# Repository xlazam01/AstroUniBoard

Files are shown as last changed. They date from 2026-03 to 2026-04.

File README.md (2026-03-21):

# AstroUniBoard

A custom STM32G0B1-based telescope controller board focused on **focuser and rotator control**. Firmware is a port of [OnStepX](https://groups.io/g/onstep/wiki/home) to a custom PCB, with added SHT31 weather sensor support and DFU bootloader management.

## Repository Structure

```
AstroUniBoard/
├── FW/                     # Firmware (PlatformIO / Arduino / OnStepX)
│   ├── src/                # OnStepX source tree + custom config
│   ├── platformio.ini      # Build configuration
│   └── tools/              # Firmware manager MCP server (DFU upload)
├── HW/                     # Hardware (PCB designs, schematics — KiCad)
└── docs/
    ├── HARDWARE.md         # Pin assignments and hardware overview
    └── FIRMWARE.md         # Build and upload guide
```

## Hardware

| | |
|---|---|
| **MCU** | STM32G0B1CBT6 (ARM Cortex-M0+ @ 64 MHz) |
| **Flash / RAM** | 128 KB / 144 KB SRAM |
| **Package** | 48-pin LQFP |
| **Stepper Drivers** | 2× TMC2209 (UART, shared bus) |
| **NV Storage** | 24AA64 I2C EEPROM (8 KB) |
| **Weather Sensor** | SHT31 (temperature + humidity, I2C) |
| **Interface** | USB CDC (native USB PA11/PA12) |
| **Upload** | DFU bootloader (ROM) |

### Axes

| Axis | Function | Driver | UART Address |
|---|---|---|---|
| AXIS3 | Rotator | TMC2209 | 1 |
| AXIS4 | Focuser | TMC2209 | 0 |

Mount axes (AXIS1/AXIS2) are disabled — this board is focuser/rotator only.

See [docs/HARDWARE.md](docs/HARDWARE.md) for full pin assignments.

## Firmware

Based on **OnStepX** — advanced telescope controller firmware with LX200 protocol compatibility, ASCOM support, and stepper motor control.

### Custom additions in this port

- `STM32G0B1.h` — HAL implementation for STM32G0B1CBT6
- `Pins.AUB_FocRot.h` — Custom pinmap (model AUB_FOCROT = 25)
- SHT31 weather sensor support (not in upstream OnStepX)
- `:EDFU#` command — jump to DFU ROM bootloader for firmware updates
- Activity LED (PB4) driven by focuser/rotator movement

### Build status

- Flash: **93.3%** (122,244 / 131,072 bytes)
- RAM: **8.2%**
- Compiler: ARM GCC, `-Os -std=gnu++17`
- Hardware tested and functional

### Quick start

1. Install [PlatformIO](https://platformio.org/)
2. Open the `FW/` folder in VS Code
3. Build: `Ctrl+Alt+B` (environment: `nucleo_g0b1re`)
4. First upload: put board in DFU via BOOT0 switch, then `Ctrl+Alt+U`
5. Subsequent uploads: send `:EDFU#` via serial to enter DFU, then upload

See [docs/FIRMWARE.md](docs/FIRMWARE.md) for full build and upload instructions.

## Serial Commands

| Command | Action |
|---|---|
| `:EDFU#` | Jump to DFU ROM bootloader (firmware upload) |
| `:ERESET#` | Reset MCU |
| `:ENVRESET#` | Wipe NV memory (takes effect on next boot) |

Plus the full [OnStepX LX200 command set](https://groups.io/g/onstep/wiki/OnStep-Command-Reference).

## Communication

- **Port:** USB CDC (virtual COM port, no driver needed on Linux/Mac; WinUSB on Windows)
- **Baud rate:** 115200
- **Protocol:** LX200 / OnStepX command set
- **Compatible clients:** ASCOM OnStep driver, INDI OnStep driver, Android OnStep apps, Sky Planetarium

## Tools

### Firmware Manager MCP Server

`FW/tools/firmware_manager/server.py` — MCP server that automates DFU firmware updates from Claude Code or any MCP client.

```bash
pip install -r FW/tools/firmware_manager/requirements.txt
python FW/tools/firmware_manager/server.py
```

Key tool: `enter_dfu_and_upload(port, firmware_path)` — sends `:EDFU#`, waits for re-enumeration, uploads via dfu-util.

## License

Firmware is licensed under the GPL (inherited from OnStepX). See [FW/src/LICENSE](FW/src/LICENSE).

## Credits

- OnStepX firmware by [Howard Dutton](http://www.stellarjourney.com) and contributors
- STM32G0B1 HAL port and AstroUniBoard hardware by the project author

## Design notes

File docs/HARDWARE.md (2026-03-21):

# AstroUniBoard — Hardware Reference

## MCU

| Property | Value |
|---|---|
| Part | STM32G0B1CBT6 |
| Architecture | ARM Cortex-M0+ |
| Clock | 64 MHz |
| Flash | 128 KB |
| RAM | 144 KB SRAM |
| Package | 48-pin LQFP |

## Motor Control

| Function | Pin | Notes |
|---|-----|---|
| AXIS3 ENABLE | PB7 | Rotator — active LOW |
| AXIS3 DIR | PB8 | Rotator |
| AXIS3 STEP | PB9 | Rotator |
| AXIS4 ENABLE | PB0 | Focuser — active LOW |
| AXIS4 DIR | PB1 | Focuser |
| AXIS4 STEP | PB2 | Focuser |

OnStepX axis convention: AXIS3 = Rotator, AXIS4 = Focuser. AXIS1/AXIS2 (mount) are disabled.

## TMC2209 UART (shared bus, USART2)

| Function | Pin | Notes |
|---|-----|---|
| TX | PA2 | USART2 TX, shared by both drivers |
| RX | PA3 | USART2 RX, shared by both drivers |

Baud rate: 460800. TMC2209 addresses hardwired via MS1/MS2: AXIS3 = addr 1, AXIS4 = addr 0.

## I2C Bus

| Function | Pin | Notes |
|---|-----|---|
| SCL | PA9 | 24AA64 EEPROM + SHT31 sensor |
| SDA | PA10 | 24AA64 EEPROM + SHT31 sensor |

| Device | Address | Purpose |
|---|---|---|
| 24AA64 | 0x50 | 8 KB NV storage (focuser/rotator position, settings) |
| SHT31 | 0x44 | Temperature + humidity sensor |

## USB (Native USB CDC)

| Function | Pin | Notes |
|---|-----|---|
| USB D- | PA11 | |
| USB D+ | PA12 | |

Appears as virtual COM port. Baud rate: 115200.

## Status & UI

| Function | Pin | Active | Notes |
|---|-----|---|---|
| Status LED | PB12 | LOW | Power/status indicator |
| Activity LED | PB4 | LOW | Blinks during focuser/rotator movement |
| Button LEFT | PA14 | — | Reserved, not used |
| Button RIGHT | PB6 | — | Reserved, not used |

## Auxiliary / Reserved

| Function | Pin | Notes |
|---|-----|---|
| UART6 TX | PA4 | Reserved for future use |
| UART6 RX | PA5 | Reserved for future use |
| LIMIT | PA1 | Not used |
| AUX1 | PC13 | Not used |
| AUX2 | PC14 | Not used |
| AXIS3 DIAG | PA7 | TMC2209 diag pin, not used |

## PlatformIO Board Mapping

The board is built using the `btt_ebb42_v1_1` PlatformIO target — this board uses the same STM32G0B1CBT6 chip and provides the correct STM32duino support. DFU upload targets flash address `0x08000000`.

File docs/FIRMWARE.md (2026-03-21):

# AstroUniBoard — Firmware Build & Upload Guide

## Prerequisites

- [VS Code](https://code.visualstudio.com/) with [PlatformIO extension](https://platformio.org/install/ide?install=vscode)
- Open the `FW/` folder as the PlatformIO project root

## Build

Open `FW/` in VS Code and use PlatformIO:

- **GUI:** PlatformIO sidebar → `nucleo_g0b1re` environment → Build
- **Keyboard:** `Ctrl+Alt+B`
- **CLI:** `pio run -e nucleo_g0b1re`

Build output: `FW/.pio/build/nucleo_g0b1re/firmware.bin`

### Build configuration summary

| Setting | Value |
|---|---|
| Platform | ststm32 |
| Board | btt_ebb42_v1_1 |
| Framework | Arduino |
| Upload protocol | DFU |
| Optimization | `-Os -std=gnu++17` |
| USB CDC flags | `-DUSBCON -DUSBD_USE_CDC -DHAL_PCD_MODULE_ENABLED` |

### Flash budget

| Metric | Value |
|---|---|
| Flash used | 122,244 / 131,072 bytes (93.3%) |
| RAM used | ~8.2% |

> Debug level must stay at `ON`, not `VERBOSE`. VERBOSE adds ~15 KB of string literals and overflows the 128 KB flash.

## Upload

### Via DFU (normal workflow)

1. Connect the board via USB
2. Send `:EDFU#` via any serial terminal at 115200 baud
   - Board disconnects from CDC and re-enumerates as STM32 DFU device
3. Upload: `Ctrl+Alt+U` in VS Code, or the Firmware Manager tool (see below)
4. Board auto-resets and runs new firmware
5. **Note:** "Error 74" at end of DFU upload is harmless (DFU leave status quirk)

### First upload (no firmware yet)

Board has no `:EDFU#` command, so enter DFU manually:

1. Hold BOOT0 switch, press RESET (or power-cycle with BOOT0 held)
2. Release BOOT0 — board enumerates as STM32 DFU device
3. Upload with `Ctrl+Alt+U`

### Firmware Manager MCP Server (automated)

`FW/tools/firmware_manager/server.py` provides an MCP server for one-step DFU upload from Claude Code.

```bash
pip install -r FW/tools/firmware_manager/requirements.txt
python FW/tools/firmware_manager/server.py
```

**Recommended:** `enter_dfu_and_upload(port, firmware_path)` — handles the full workflow.

```python
enter_dfu_and_upload(
    "COM6",
    "f:/Projekty/AstroUniBoard/FW/.pio/build/nucleo_g0b1re/firmware.bin"
)
```

Available tools:

| Tool | Description |
|---|---|
| `list_ports()` | List available COM ports |
| `enter_dfu(port)` | Send `:EDFU#` command |
| `upload_firmware(firmware_path)` | Upload .bin via dfu-util (device must already be in DFU) |
| `enter_dfu_and_upload(port, path, wait_seconds=3)` | Complete workflow (recommended) |
| `build_firmware(project_dir, environment)` | Build via PlatformIO CLI |
| `serial_read(port, baudrate, duration_seconds)` | Read serial output |

## Configuration

### Primary: `FW/src/Config.h`

```c
#define PINMAP          AUB_FOCROT    // Custom board
#define SERIAL_A_BAUD   115200        // USB CDC
#define WEATHER         SHT31         // I2C 0x44
#define STATUS_LED      ON
#define AXIS1_DRIVER_MODEL  OFF       // No mount
#define AXIS2_DRIVER_MODEL  OFF       // No mount
#define AXIS3_DRIVER_MODEL  TMC2209   // Rotator
#define AXIS4_DRIVER_MODEL  TMC2209   // Focuser
```

### Extended: `FW/src/Extended.config.h`

```c
#define DEBUG           ON            // Use ON, never VERBOSE
#define SERIAL_DEBUG    SerialUSB
#define NV_WIPE         OFF
```

## Serial Commands

| Command | Action |
|---|---|
| `:EDFU#` | Jump to DFU ROM bootloader |
| `:ERESET#` | Reset MCU |
| `:ENVRESET#` | Wipe NV memory on next boot |

Full OnStepX LX200 command set applies for focuser and rotator control.

## Troubleshooting

### "No DFU capable USB device available"
Device not in DFU mode yet. Increase `wait_seconds` to 4–5, or check BOOT0.

### "could not open port COMX"
Port is in use. Close any serial monitors before uploading.

### Board not responding after upload
Check that `SerialUSB` (not `Serial`) is used for USB CDC. The firmware uses `SerialUSB` explicitly.

### dfu-util not found
PlatformIO bundles dfu-util. Path: `C:\Users\<user>\.platformio\packages\tool-dfuutil\bin\dfu-util.exe`

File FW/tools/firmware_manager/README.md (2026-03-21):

# Firmware Manager MCP Server

Manages firmware updates and DFU mode entry for the AstroUniBoard FocuserRotator (OnStepX).

## Prerequisite
- `dfu-util` must be installed (bundled with PlatformIO)
- `pip install -r requirements.txt`

## Tools

### `list_ports()`
List available COM ports.

**Returns:** List of port names

---

### `enter_dfu(port)`
Send `:EDFU#` command to jump to bootloader.

**Parameters:**
- `port` (str): Serial port (e.g., "COM6")

**Returns:** Status message

**Note:** Device will reboot into DFU mode. Wait 2-3 seconds before uploading.

---

### `upload_firmware(firmware_path)`
Upload firmware using dfu-util.

**Parameters:**
- `firmware_path` (str): Absolute path to .bin firmware file

**Returns:** Upload status and output

**Example:**
```python
upload_firmware("f:/Projekty/AstroUniBoard/FW - FocuserRotator/.pio/build/nucleo_g0b1re/firmware.bin")
```

---

### `enter_dfu_and_upload(port, firmware_path, wait_seconds=3)` - **RECOMMENDED**
Complete workflow: Send DFU command -> Wait -> Upload firmware.

**Parameters:**
- `port` (str): Serial port (e.g., "COM6")
- `firmware_path` (str): Absolute path to .bin firmware file
- `wait_seconds` (int): Seconds to wait after DFU command (default: 3)

**Returns:** Complete workflow status

**Example:**
```python
enter_dfu_and_upload(
    "COM6",
    "f:/Projekty/AstroUniBoard/FW - FocuserRotator/.pio/build/nucleo_g0b1re/firmware.bin",
    3
)
```

---

## Usage

### Starting the Server
```bash
python tools/firmware_manager/server.py
```

### Typical Workflow

**Option 1: All-in-one (Recommended)**
```python
enter_dfu_and_upload(
    "COM6",
    "f:/Projekty/AstroUniBoard/FW - FocuserRotator/.pio/build/nucleo_g0b1re/firmware.bin"
)
```

**Option 2: Manual steps**
```python
# Step 1: Send DFU command
enter_dfu("COM6")

# Step 2: Wait manually (3 seconds)

# Step 3: Upload
upload_firmware("f:/Projekty/AstroUniBoard/FW - FocuserRotator/.pio/build/nucleo_g0b1re/firmware.bin")
```

---

## Troubleshooting

### "No DFU capable USB device available"
**Cause:** Device not in DFU mode yet
**Solution:**
- Increase `wait_seconds` parameter (try 4-5 seconds)
- Manually reset device before upload

### "could not open port 'COMX'"
**Cause:** Port is in use
**Solution:**
- Close any serial monitors
- Close VSCode serial monitor
- Wait for port to be released

### "dfu-util not found"
**Cause:** dfu-util not in PATH
**Solution:**
- Verify path: `c:\Users\marti\.platformio\packages\tool-dfuutil\bin\dfu-util.exe`
- Server uses hardcoded path, should work automatically

---

## Configuration

The server is pre-configured for your environment:
- **DFU command:** `:EDFU#` (OnStepX custom command)
- **Serial baud:** 115200
- **dfu-util path:** `c:\Users\marti\.platformio\packages\tool-dfuutil\bin\dfu-util.exe`
- **Upload address:** `0x08000000` (STM32 flash start)
- **Upload mode:** `:leave` (device auto-reboots after upload)
- **Build output:** `.pio/build/nucleo_g0b1re/firmware.bin`

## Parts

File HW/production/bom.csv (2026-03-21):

Designator | Footprint | Quantity | Value | LCSC Part #
C1, C10, C11, C33 | 0402 | 4 | 1uF
C12, C15, C17, C8, C9 | 0402 | 5 | 100nF
C13, C16, C29 | 0805 | 3 | 10u/25V
C14, C31, C32 | 0402 | 3 | 10uF
C18, C7 | 0402 | 2 | 22n/50V
C19, C20, C21, C22, C23, C25, C26, C27, C30 | 0402 | 9 | 100n/50V
C2, C3 | 0805 | 2 | 10uF/25V
C24, C28 | 0402 | 2 | 10uF/10V
C4, C5 | 0402 | 2 | 10pF
C6 | 0402 | 1 | 100n
D1, D2, D3, D4 | 0603 | 4 | LED RED 0603
D23 | D_SMA | 1 | D_Small
F1, F2 | 0603 | 2 | SMD0603P050TF
H1, H2, H3, H4 | MountingHole_2.2mm_M2_DIN965_Pad | 4 | MountingHole_Pad
H5, H6, H7, H8 | MountingHole_3.2mm_M3_DIN965_Pad | 4 | MountingHole_Pad
J10, J3, J5, J8, J9 | JST_PH_B4B-PH-K_1x04_P2.00mm_Vertical | 5 | Conn_01x04
J2, J7 | USB_C_Receptacle_G-Switch_GT-USB-7010ASV | 2 | MC-311D
J4 | JST_PH_B3B-PH-K_1x03_P2.00mm_Vertical | 1 | Conn_01x03
J6 | BarrelJack_GCT_DCJ200-10-A_Horizontal | 1 | 5.5/2.1 Barell DC2
L4 | L_5.5x5.1mm | 1 | L_Small
LEFT/BOOT1, RIGHT1, RST1 | SW_Push_SPST_NO_Alps_SKRK | 3 | TS-1088-AR02016
R1, R2 | 0402 | 2 | 22R
R10, R11, R19, R20 | 0805 | 4 | 0.11R/0805
R12, R24 | 0402 | 2 | 1k
R13, R15, R27, R3, R4, R5, R9 | 0402 | 7 | 10k
R14, R18, R6 | 0402 | 3 | 510R
R16, R17, R7, R8 | 0402 | 4 | 5k1
R21 | 0402 | 1 | 100k
R22 | 0402 | 1 | 6k34(10k7)
R23 | 0402 | 1 | 2k
R25, R26 | 0402 | 2 | 22k
TP1, TP2, TP3 | TestPoint_Micro | 3 | TestPoint
U1 | SOT-23 | 1 | ME6231
U12 | SOT-23-6 | 1 | ME3116
U2, U3 | QFN-28-1EP_5x5mm_P0.5mm_EP3.75x3.75mm_ThermalVias | 2 | ~
U4 | SOT-23-5 | 1 | 24AA64T-I/OT
U5 | LQFP-48_7x7mm_P0.5mm | 1 | STM32G0B1CBTx
U6 | LQFN-16-1EP_3x3mm_P0.5mm_EP1.7x1.7mm | 1 | CH334P
U8 | Sensirion_DFN-8-1EP_2.5x2.5mm_P0.5mm_EP1.1x1.7mm | 1 | SHT31A-DIS
Y1 | Crystal_SMD_3225-4Pin_3.2x2.5mm | 1 | TAXM8M4RDBCCT2T / 8MHz
Y2 | Crystal_SMD_3225-4Pin_3.2x2.5mm | 1 | TAXM12M4RDBCCT2T / 12MHz

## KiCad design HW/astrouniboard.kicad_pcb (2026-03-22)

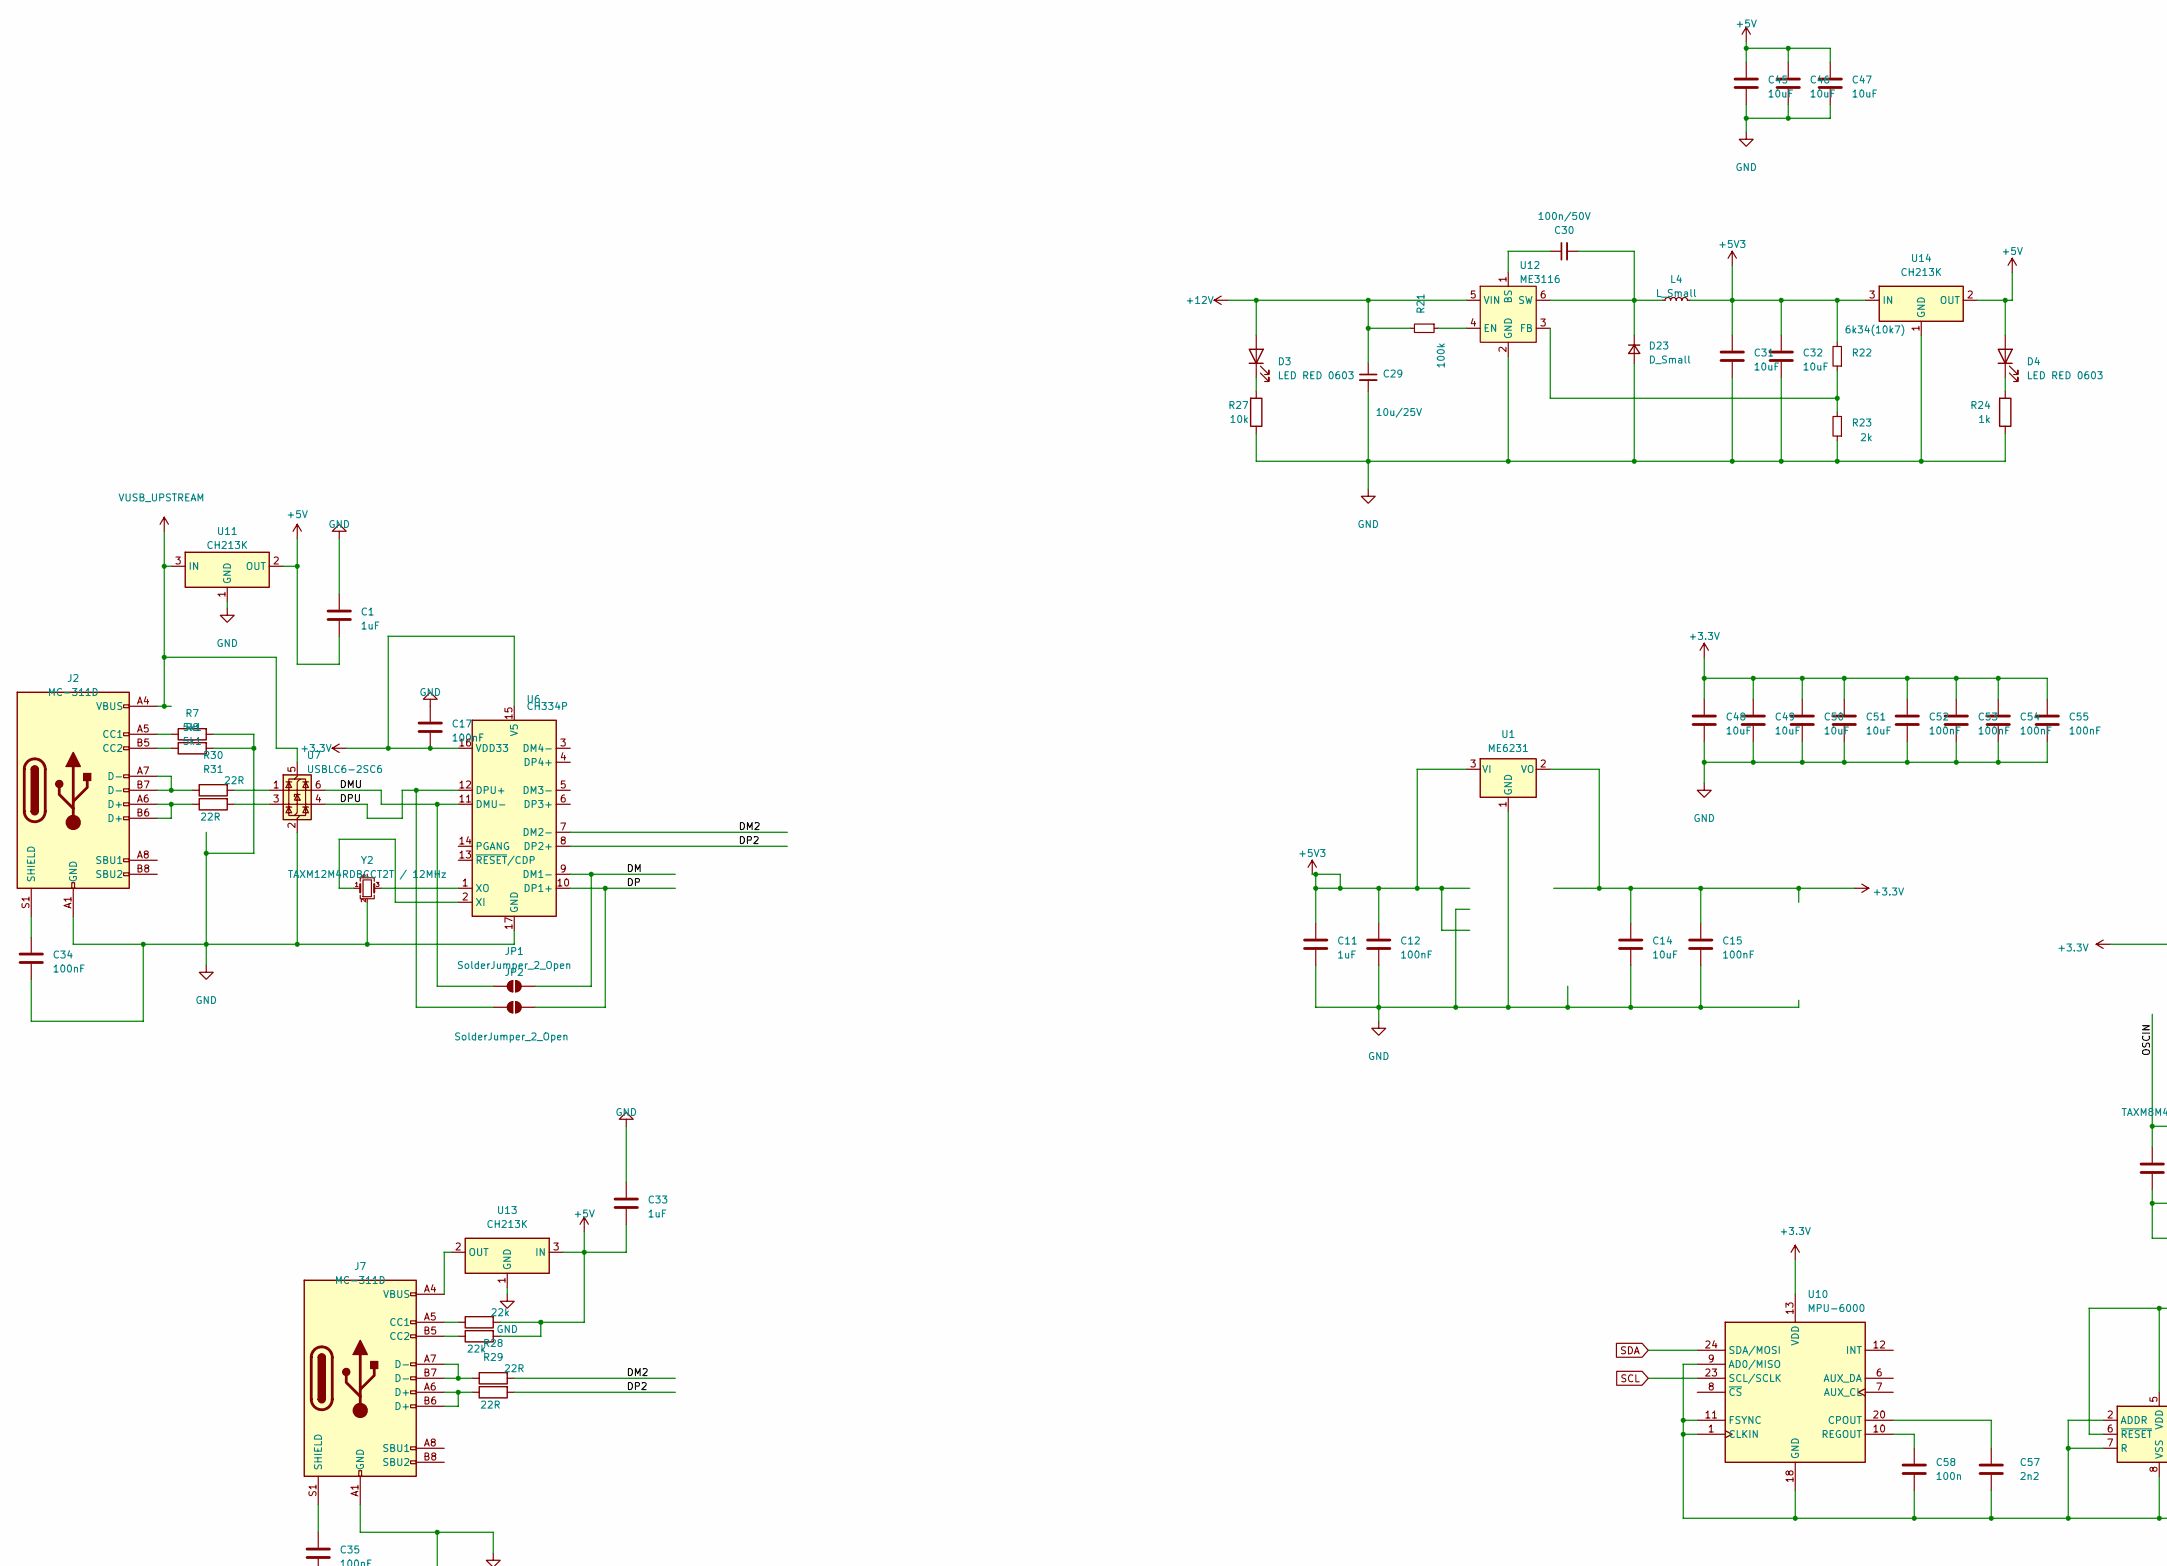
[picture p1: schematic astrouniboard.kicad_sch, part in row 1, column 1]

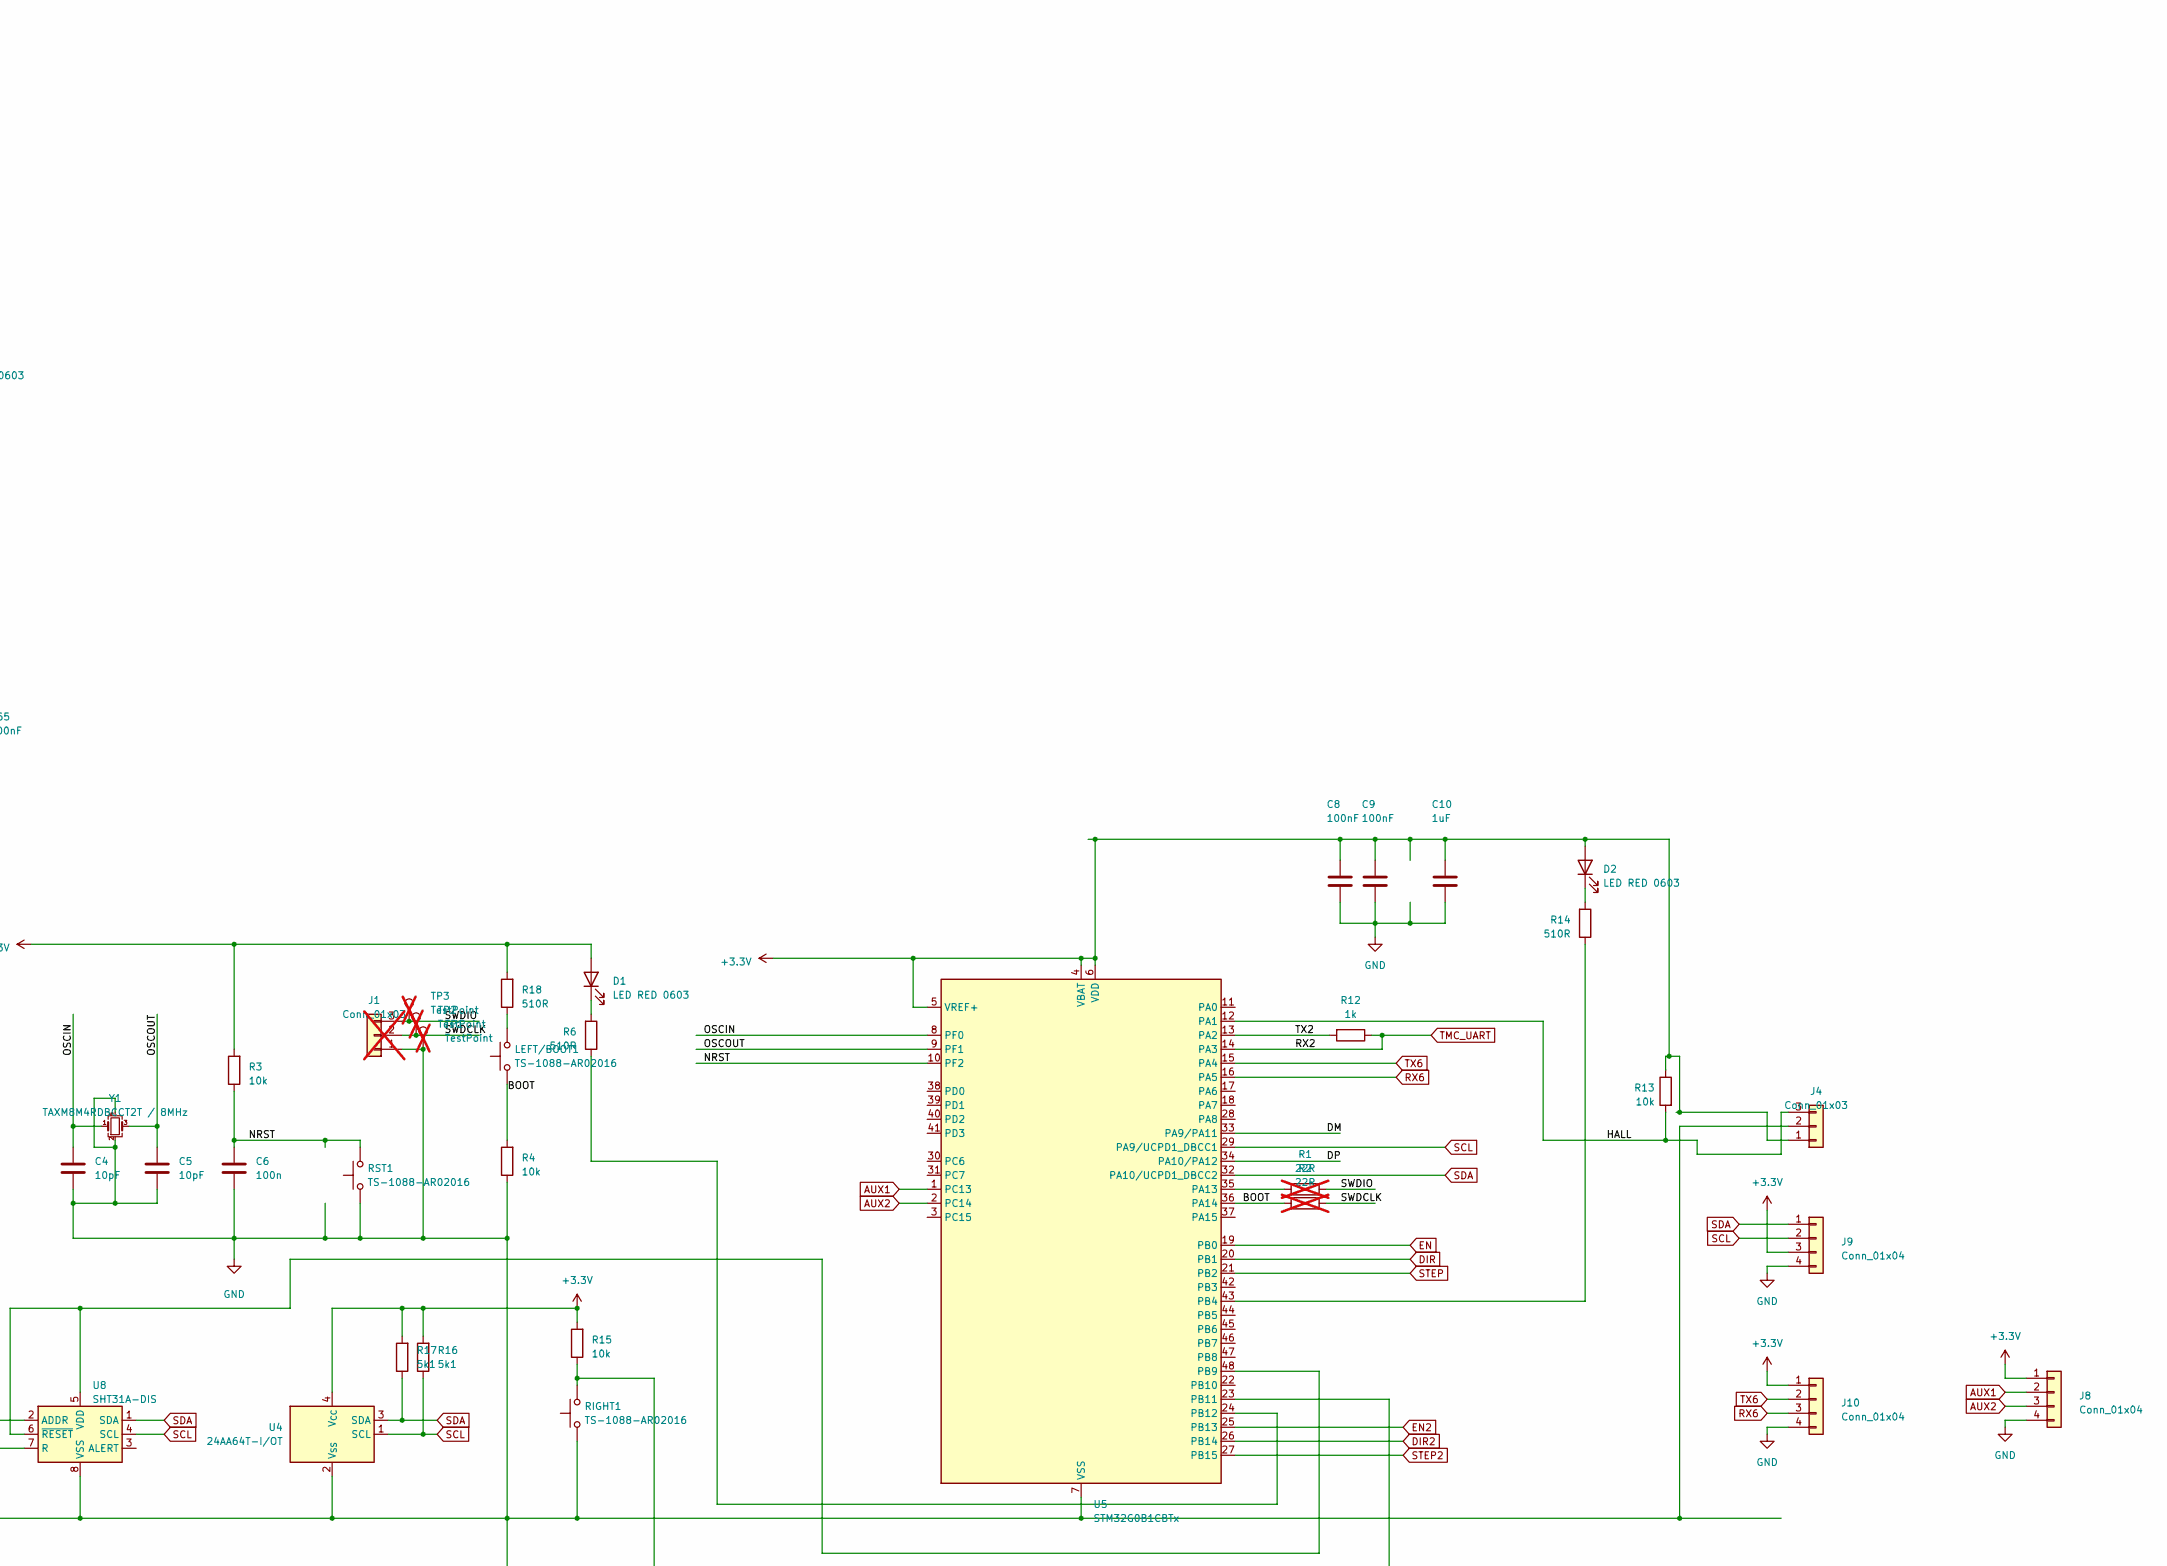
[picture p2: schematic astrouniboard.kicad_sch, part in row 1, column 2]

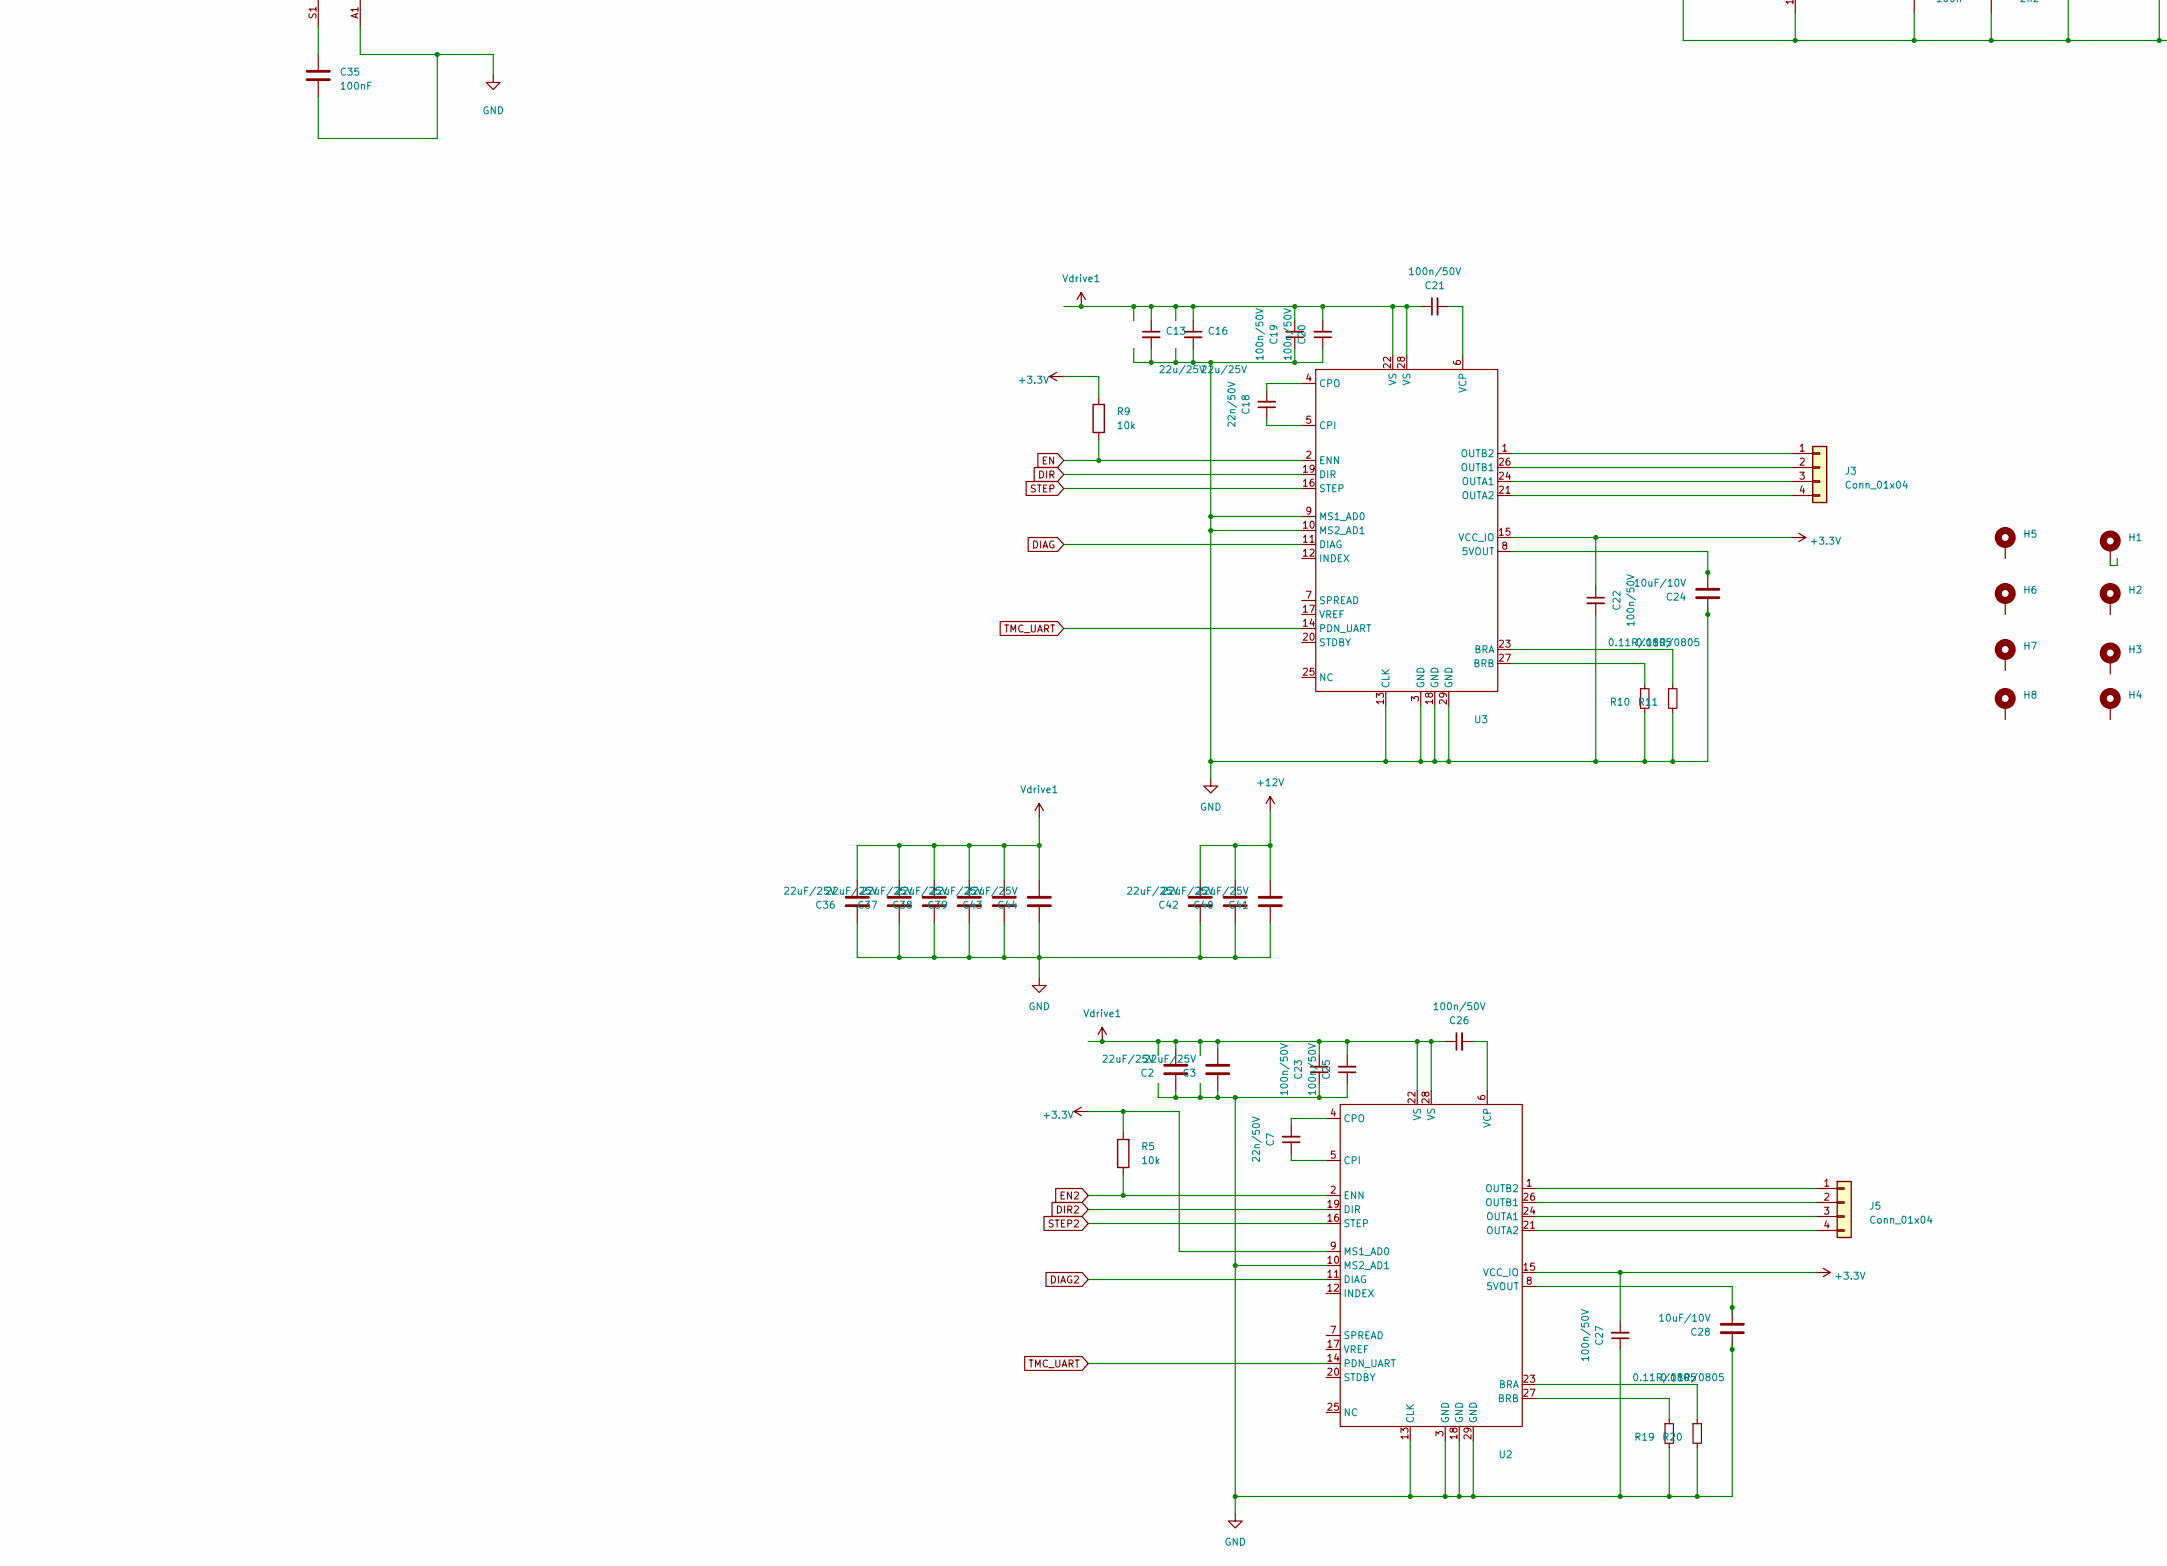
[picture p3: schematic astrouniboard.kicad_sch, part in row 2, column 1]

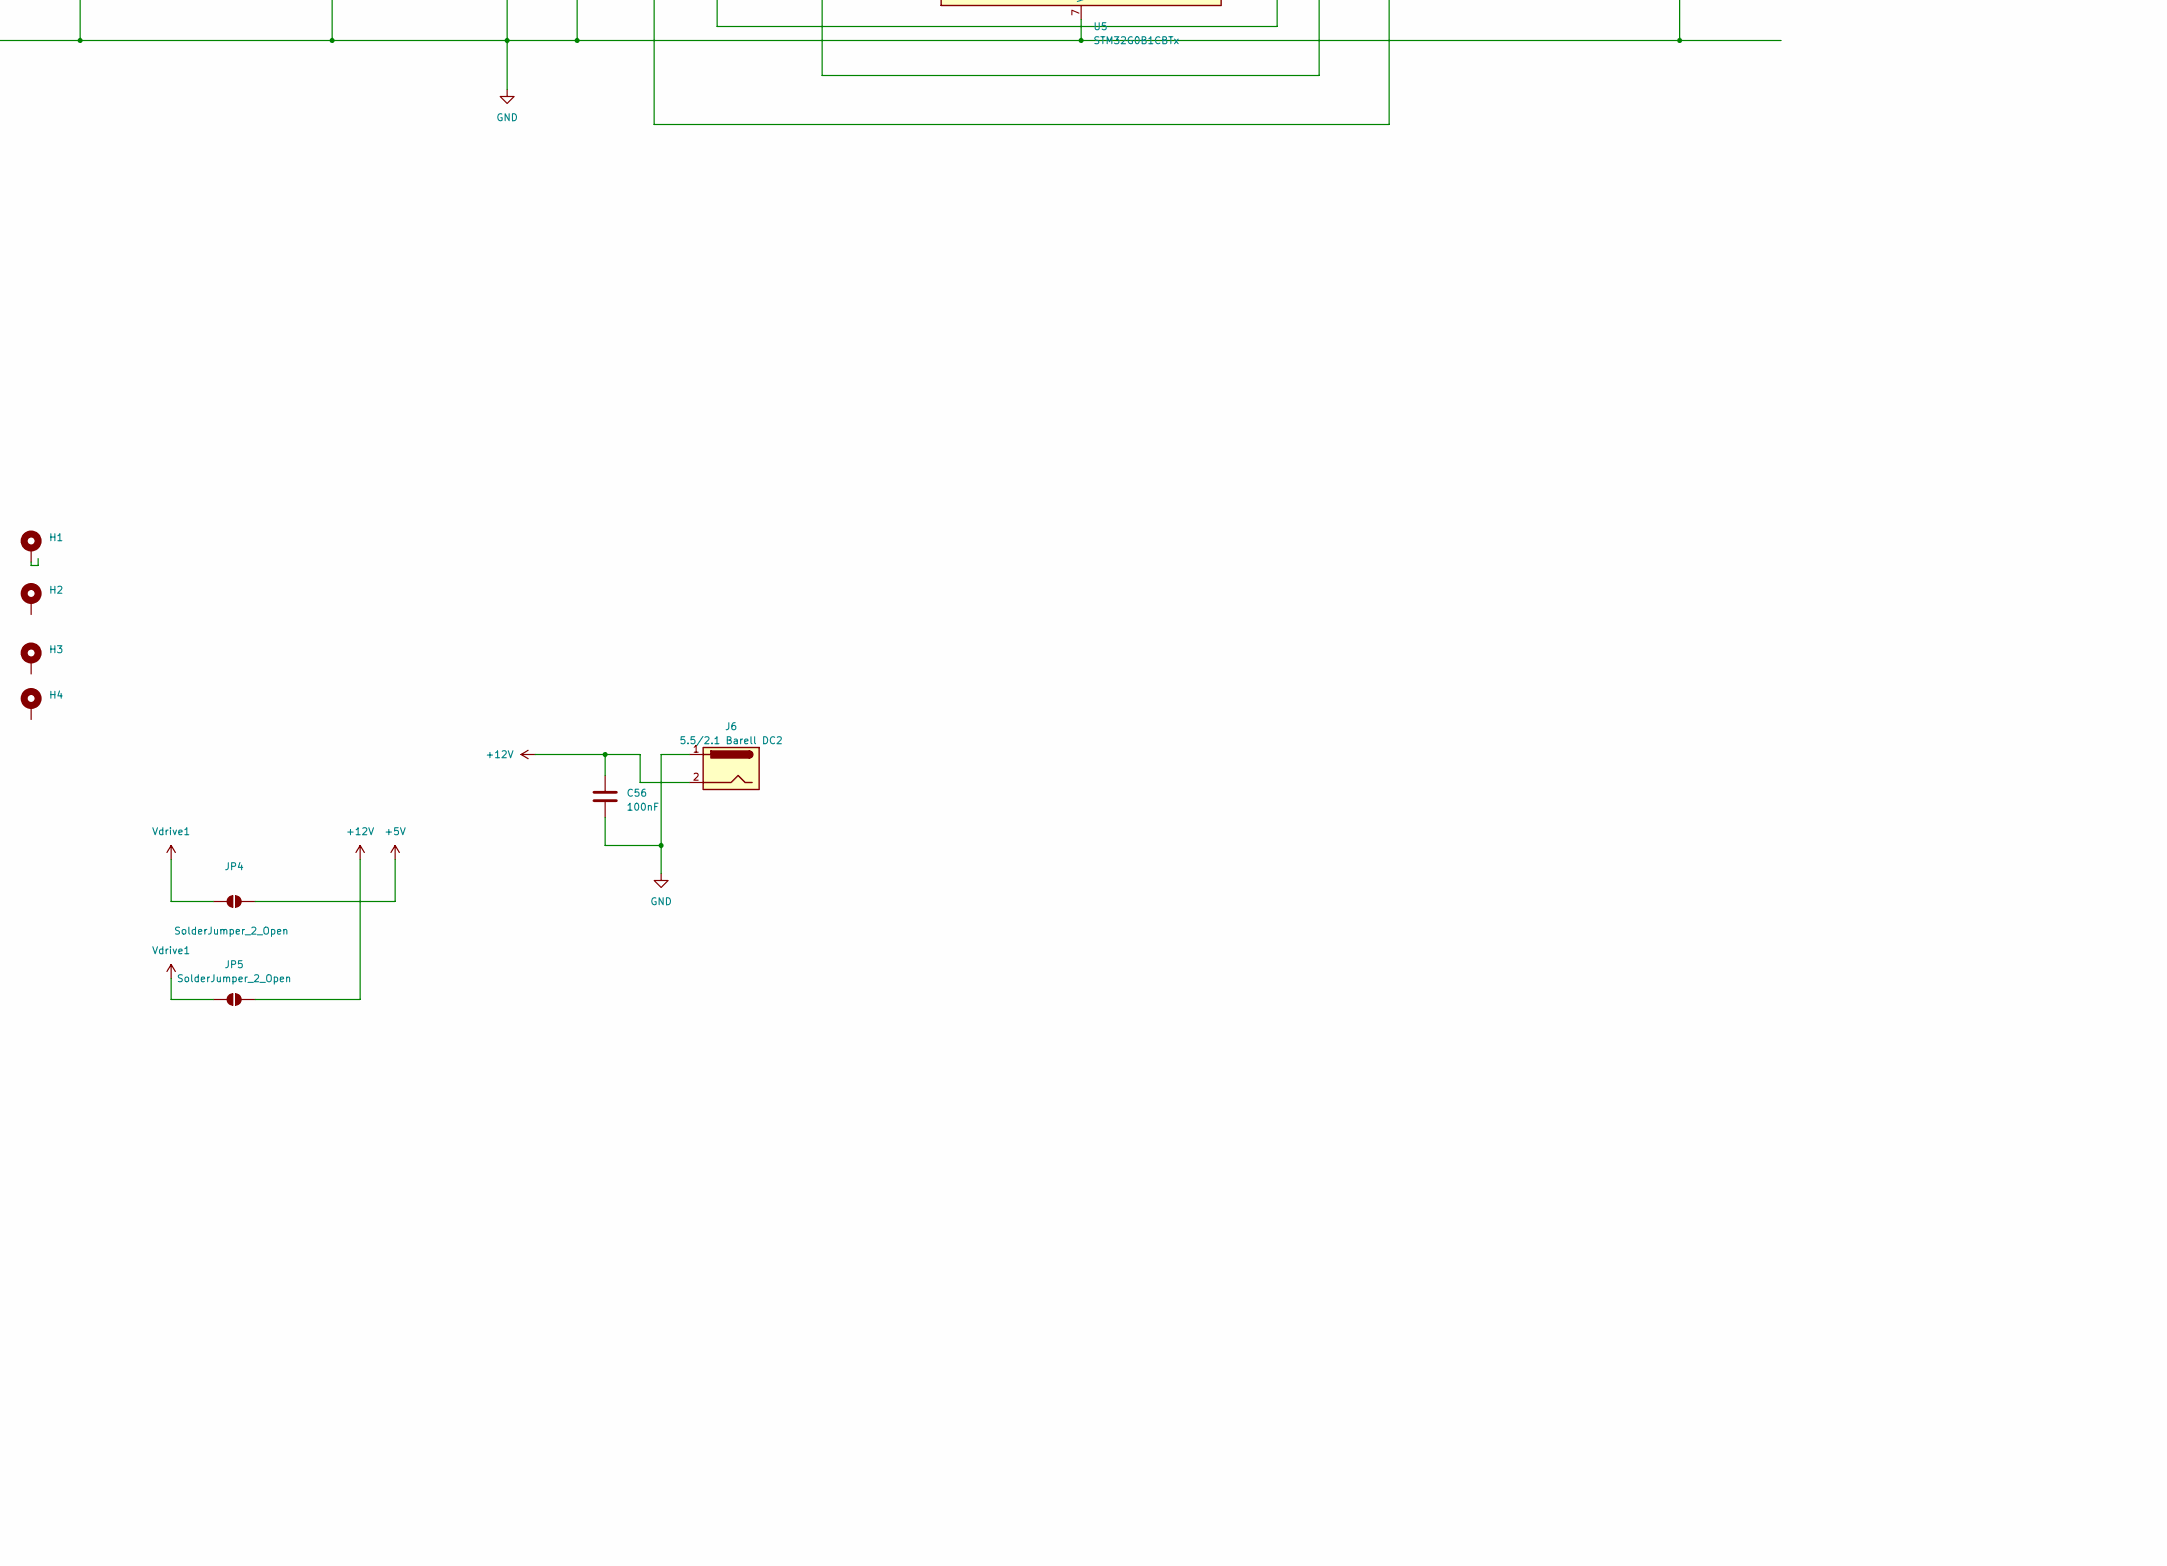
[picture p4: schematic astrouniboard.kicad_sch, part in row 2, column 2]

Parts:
C1, C10, C11, C33: 1uF; C_0402_1005Metric
C2, C3, C36, C37, C38, C39, C40, C41, C42, C43, C44: 22uF/25V; C_0805_2012Metric
C4, C5: 10pF; C_0402_1005Metric
C6, C58: 100n; C_0402_1005Metric
C7, C18: 22n/50V; C_0402_1005Metric
C8, C9, C12, C15, C17, C34, C35, C52, C53, C54, C55, C56: 100nF; C_0402_1005Metric
C13, C16: 22u/25V; C_0805_2012Metric
C14, C31, C32, C45, C46, C47, C48, C49, C50, C51: 10uF; C_0402_1005Metric
C19, C20, C21, C22, C23, C25, C26, C27, C30: 100n/50V; C_0402_1005Metric
C24, C28: 10uF/10V; C_0402_1005Metric
C29: 10u/25V; C_0805_2012Metric
C57: 2n2; C_0402_1005Metric
D1, D2, D3, D4: LED RED 0603; LED_0402_1005Metric
D23: D_Small; D_SMA
H1, H2, H3, H4: MountingHole_Pad; MountingHole_2.2mm_M2_DIN965_Pad
H5, H6, H7, H8: MountingHole_Pad; MountingHole_3.2mm_M3_DIN965_Pad
J1: Conn_01x03; JST_PH_B3B-PH-K_1x03_P2.00mm_Vertical; not fitted
J2, J7: MC-311D; USB_C_Receptacle_G-Switch_GT-USB-7010ASV
J3, J8, J9, J10: Conn_01x04; JST_PH_B4B-PH-K_1x04_P2.00mm_Vertical
J4: Conn_01x03; JST_PH_B3B-PH-K_1x03_P2.00mm_Vertical
J5: Conn_01x04; JST_PH_S4B-PH-K_1x04_P2.00mm_Horizontal
J6: 5.5/2.1 Barell DC2; AMASS_XT30PW-M_1x02_P2.50mm_Horizontal
JP1, JP2: SolderJumper_2_Open; Micro SolderJumper
JP4, JP5: SolderJumper_2_Open; SolderJumper-2_P1.3mm_Open_RoundedPad1.0x1.5mm
L4: L_Small; L_5.5x5.1mm
LEFT/BOOT1: TS-1088-AR02016; SW_Push_SPST_NO_Alps_SKRK
R1, R2: 22R; R_0402_1005Metric; not fitted
R3, R4, R5, R9, R13, R15, R27: 10k; R_0402_1005Metric
R6, R14, R18: 510R; R_0402_1005Metric
R7, R8, R16, R17: 5k1; R_0402_1005Metric
R10, R11, R19, R20: 0.11R/0805; R_0805_2012Metric
R12, R24: 1k; R_0402_1005Metric
R21: 100k; R_0402_1005Metric
R22: 6k34(10k7); R_0402_1005Metric
R23: 2k; R_0402_1005Metric
R25, R26: 22k; R_0402_1005Metric
R28, R29, R30, R31: 22R; R_0402_1005Metric
RIGHT1: TS-1088-AR02016; SW_Push_SPST_NO_Alps_SKRK
RST1: TS-1088-AR02016; SW_Push_SPST_NO_Alps_SKRK
TP1, TP2, TP3: TestPoint; TestPoint_Micro; not fitted
U1: ME6231; SOT-23
U2, U3: QFN-28-1EP_5x5mm_P0.5mm_EP3.75x3.75mm_ThermalVias
U4: 24AA64T-I/OT; SOT-23-5
U5: STM32G0B1CBTx; LQFP-48_7x7mm_P0.5mm
U6: CH334P; LQFN-16-1EP_3x3mm_P0.5mm_EP1.7x1.7mm
U7: USBLC6-2SC6; SOT-23-6
U8: SHT31A-DIS; Sensirion_DFN-8-1EP_2.5x2.5mm_P0.5mm_EP1.1x1.7mm
U10: MPU-6000; InvenSense_QFN-24_4x4mm_P0.5mm
U11, U13, U14: CH213K; SOT-23
U12: ME3116; SOT-23-6
Y1: TAXM8M4RDBCCT2T / 8MHz; Crystal_SMD_3225-4Pin_3.2x2.5mm
Y2: TAXM12M4RDBCCT2T / 12MHz; Crystal_SMD_3225-4Pin_3.2x2.5mm

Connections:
+3.3V: C8.1, C9.1, C10.1, C14.1, C15.1, C17.2, C22.1, C27.2, C48.1, C49.1, C50.1, C51.1, C52.1, C53.1, C54.1, C55.1, D1.2 (A), D2.2 (A), J4.1, J8.1, J9.3, J10.1, R3.2, R5.2, R9.2, R13.1, R15.2, R16.2, R17.2, R18.2, U1.2 (VO), U2.9 (MS1_AD0), U2.15 (VCC_IO), U3.15 (VCC_IO), U4.4 (V_{CC}), U5.4 (VBAT), U5.5 (VREF+), U5.6 (VDD), U6.15 (V5), U6.16 (VDD33), U10.13 (VDD)
+5V: C1.2, C33.2, C45.1, C46.1, C47.1, D4.2 (A), JP4.2 (B), R25.2, R26.2, U11.2 (OUT), U13.3 (IN), U14.2 (OUT)
+5V3: C11.1, C12.1, C31.1, C32.1, L4.2, R22.2, U1.3 (VI), U14.3 (IN)
/BOOT: LEFT/BOOT1.1, R4.2, U5.36 (PA14)
/DM: JP1.2 (B), U5.33 (PA9/PA11), U6.9 (DM1-)
/DM2: R28.2, U6.7 (DM2-)
/DMU: JP1.1 (A), U6.11 (DMU-), U7.6 (I/O1)
/DP: JP2.2 (B), U5.34 (PA10/PA12), U6.10 (DP1+)
/DP2: R29.2, U6.8 (DP2+)
/DPU: JP2.1 (A), U6.12 (DPU+), U7.4 (I/O2)
/HALL: J4.3, R13.2, U5.12 (PA1)
/NRST: C6.1, R3.1, RST1.2, U5.10 (PF2)
/OSCIN: C4.1, U5.8 (PF0), Y1.1
/OSCOUT: C5.1, U5.9 (PF1), Y1.3
/TX2: R12.2, U5.13 (PA2)
AUX1: J8.2, U5.1 (PC13)
AUX2: J8.3, U5.2 (PC14)
DIAG: U3.11 (DIAG)
DIAG2: U2.11 (DIAG)
DIR: U3.19 (DIR), U5.20 (PB1)
DIR2: U2.19 (DIR), U5.26 (PB14)
EN: R9.1, U3.2 (ENN), U5.19 (PB0)
EN2: R5.1, U2.2 (ENN), U5.25 (PB13)
GND: C1.1, C2.1, C3.1, C4.2, C5.2, C6.2, C8.2, C9.2, C10.2, C11.2, C12.2, C13.2, C14.2, C15.2, C16.2, C17.1, C19.1, C20.1, C22.2, C23.1, C24.1, C25.1, C27.1, C28.1, C29.2, C31.2, C32.2, C33.1, C34.2, C35.2, C36.1, C37.1, C38.1, C39.1, C40.1, C41.1, C42.1, C43.1, C44.1, C45.2, C46.2, C47.2, C48.2, C49.2, C50.2, C51.2, C52.2, C53.2, C54.2, C55.2, C56.2, C57.2, C58.2, D23.2 (A), J2.A1 (GND), J2.A12 (GND), J2.B1 (GND), J2.B12 (GND), J4.2, J6.1, J7.A1 (GND), J7.A12 (GND), J7.B1 (GND), J7.B12 (GND), J8.4, J9.4, J10.4, R4.1, R7.2, R8.2, R10.2, R11.2, R19.2, R20.2, R23.1, R24.1, R27.1, RIGHT1.1, RST1.1, U1.1 (GND), U2.3 (GND), U2.10 (MS2_AD1), U2.13 (CLK), U2.18 (GND), U2.29 (GND), U3.3 (GND), U3.9 (MS1_AD0), U3.10 (MS2_AD1), U3.13 (CLK), U3.18 (GND), U3.29 (GND), U4.2 (V_{SS}), U5.7 (VSS), U6.17 (GND), U7.2 (GND), U8.2 (ADDR), U8.7 (R), U8.8 (VSS), U8.9 (VSS), U10.1 (CLKIN), U10.9 (AD0/MISO), U10.11 (FSYNC), U10.18 (GND), U11.1 (GND), U12.2 (GND), U13.1 (GND), U14.1 (GND), Y1.2, Y1.4, Y2.2
unnamed: D1.1 (K), R6.2
unnamed: D2.1 (K), R14.2
unnamed: D3.1 (K), R27.2
unnamed: D4.1 (K), R24.2
unnamed: C30.2, D23.1 (K), L4.1, U12.6 (SW)
unnamed: J2.A5 (CC1), R7.1
unnamed: J2.B5 (CC2), R8.1
unnamed: J2.A6 (D+), J2.B6 (D+), R31.1
unnamed: J2.A7 (D-), J2.B7 (D-), R30.1
unnamed: C34.1, J2.S1 (SHIELD)
unnamed: J3.1, U3.1 (OUTB2)
unnamed: J3.2, U3.26 (OUTB1)
unnamed: J3.3, U3.24 (OUTA1)
unnamed: J3.4, U3.21 (OUTA2)
unnamed: J5.1, U2.1 (OUTB2)
unnamed: J5.2, U2.26 (OUTB1)
unnamed: J5.3, U2.24 (OUTA1)
unnamed: J5.4, U2.21 (OUTA2)
unnamed: J7.A5 (CC1), R25.1
unnamed: J7.B5 (CC2), R26.1
unnamed: J7.A6 (D+), J7.B6 (D+), R29.1
unnamed: J7.A7 (D-), J7.B7 (D-), R28.1
unnamed: C35.1, J7.S1 (SHIELD)
unnamed: LEFT/BOOT1.2, R18.1
unnamed: J6.3, R1.1, TP3.1
unnamed: R30.2, U7.1 (I/O1)
unnamed: R31.2, U7.3 (I/O2)
unnamed: C28.2, U2.8 (5VOUT)
unnamed: R20.1, U2.23 (BRA)
unnamed: R19.1, U2.27 (BRB)
unnamed: C7.1, U2.5 (CPI)
unnamed: C7.2, U2.4 (CPO)
unnamed: C26.2, U2.6 (VCP)
unnamed: C24.2, U3.8 (5VOUT)
unnamed: R11.1, U3.23 (BRA)
unnamed: R10.1, U3.27 (BRB)
unnamed: C18.1, U3.5 (CPI)
unnamed: C18.2, U3.4 (CPO)
unnamed: C21.2, U3.6 (VCP)
unnamed: R1.2, U5.35 (PA13)
unnamed: R14.1, U5.43 (PB4)
unnamed: U5.48 (PB9), U8.5 (VDD), U8.6 (~RESET)
unnamed: R15.1, RIGHT1.2, U5.23 (PB11)
unnamed: R6.1, U5.24 (PB12)
unnamed: U6.2 (XI), Y2.1
unnamed: U6.1 (XO), Y2.3
unnamed: C57.1, U10.20 (CPOUT)
unnamed: C58.1, U10.10 (REGOUT)
unnamed: C30.1, U12.1 (BS)
unnamed: R21.1, U12.4 (EN)
unnamed: R22.1, R23.2, U12.3 (FB)
unnamed: J7.A4 (VBUS), J7.A9 (VBUS), J7.B4 (VBUS), J7.B9 (VBUS), U13.2 (OUT)
RX6: J10.3, U5.16 (PA5)
SCL: J9.2, R16.1, U4.1 (SCL), U5.29 (PA9/UCPD1_DBCC1), U8.4 (SCL), U10.23 (SCL/SCLK)
SDA: J9.1, R17.1, U4.3 (SDA), U5.32 (PA10/UCPD1_DBCC2), U8.1 (SDA), U10.24 (SDA/MOSI)
STEP: U3.16 (STEP), U5.21 (PB2)
STEP2: U2.16 (STEP), U5.27 (PB15)
TMC_UART: R12.1, U2.14 (PDN_UART), U3.14 (PDN_UART), U5.14 (PA3)
TX6: J10.2, U5.15 (PA4)
VUSB_UPSTREAM: J2.A4 (VBUS), J2.A9 (VBUS), J2.B4 (VBUS), J2.B9 (VBUS), U7.5 (VBUS), U11.3 (IN)
Vdrive1: C2.2, C3.2, C13.1, C16.1, C19.2, C20.2, C21.1, C23.2, C25.2, C26.1, C36.2, C37.2, C38.2, C39.2, C43.2, C44.2, JP4.1 (A), JP5.1 (A), U2.22 (VS), U2.28 (VS), U3.22 (VS), U3.28 (VS)

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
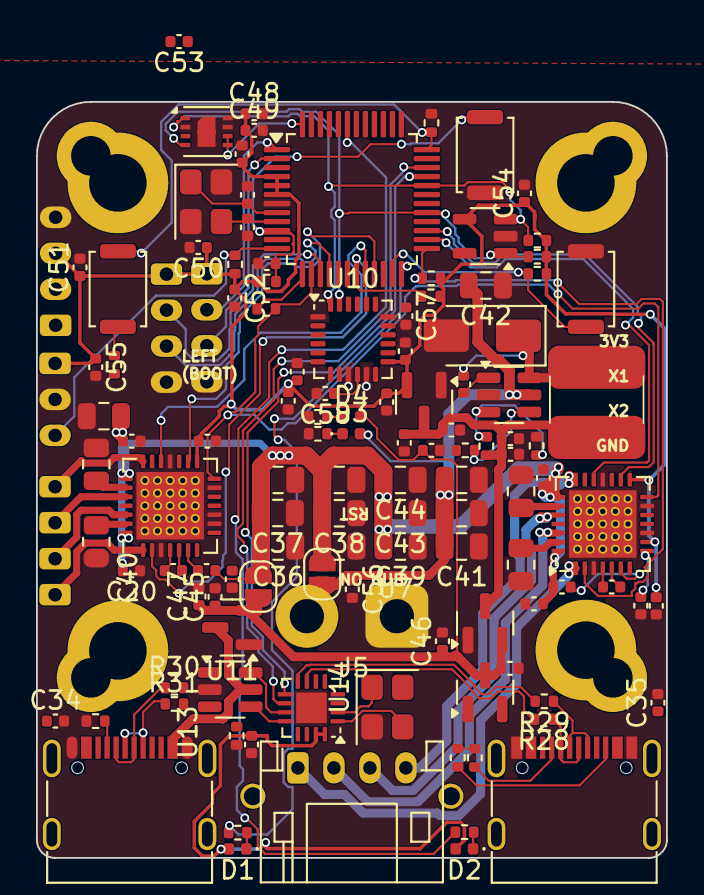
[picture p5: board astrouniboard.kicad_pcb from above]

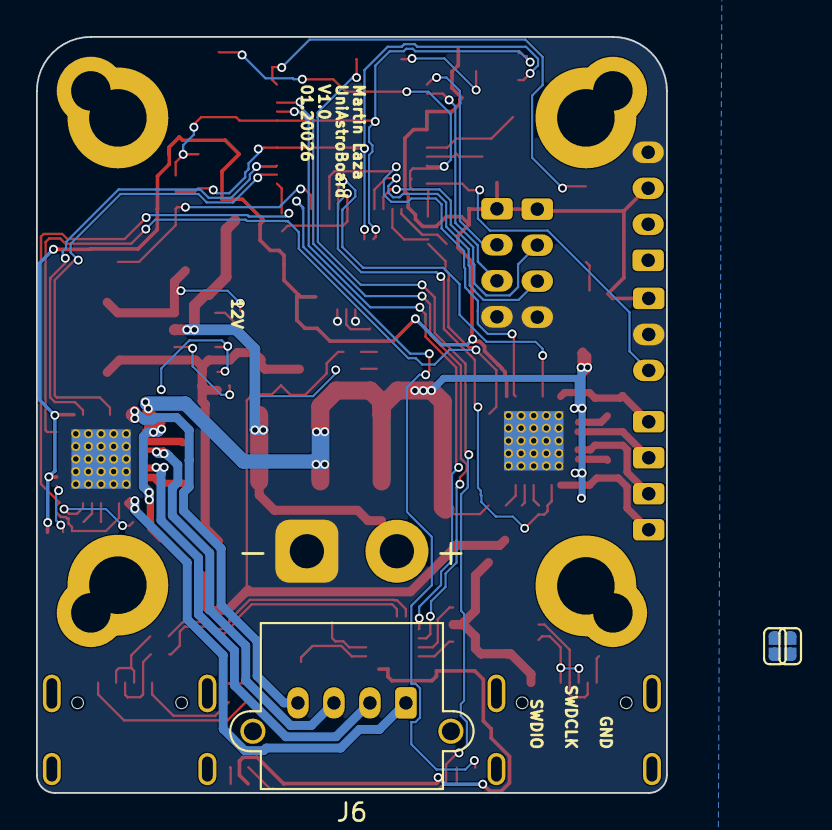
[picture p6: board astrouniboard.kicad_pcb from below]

Board: 2 copper layers, 35.0 x 42.0 mm, 132 parts (3 on the bottom side), 82 nets.

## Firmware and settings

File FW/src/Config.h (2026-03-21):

/* ---------------------------------------------------------------------------------------------------------------------------------
 * Configuration for OnStepX
 *
 *          For more information on setting OnStep up see http://www.stellarjourney.com/index.php?r=site/equipment_onstep 
 *                      and join the OnStep Groups.io at https://groups.io/g/onstep
 * 
 *           *** Read the compiler warnings and errors, they are there to help guard against invalid configurations ***
 *
 * ---------------------------------------------------------------------------------------------------------------------------------
 * ADJUST THE FOLLOWING TO CONFIGURE YOUR CONTROLLER FEATURES ----------------------------------------------------------------------
 * <-Req'd = always must set, <-Often = usually must set, Option = optional, Adjust = adjust as req'd, Infreq = infrequently changed
*/
//      Parameter Name              Value   Default  Notes                                                                      Hint

// =================================================================================================================================
// CONTROLLER ======================================================================================================================
#define HOST_NAME                "OnStep" // nStep", Hostname for this device up to 16 chars.                                 Adjust

// PINMAP ------------------------------------------------- see https://onstep.groups.io/g/main/wiki/Configuration_Controller#PINMAP
#define PINMAP                        AUB_FOCROT //    OFF, Choose from: MiniPCB, MiniPCB2, MaxPCB4, MaxESP4, MaxSTM3, FYSETC_E4,   <-Req'd
                                          //         BTT_SKR_PRO, etc.  Other boards and more info. in ~/src/Constants.h

// SERIAL PORT COMMAND CHANNELS --------------------- see https://onstep.groups.io/g/main/wiki/Configuration_Controller#SERIAL_PORTS
#define SERIAL_A_BAUD_DEFAULT        115200 //   9600, n. Where n=9600,19200,57600,115200,230400,460800 (common baud rates.)    Infreq
#define SERIAL_B_BAUD_DEFAULT         OFF //   9600, n. Baud rate as above. See (src/pinmaps/) for Serial port assignments.   Infreq
#define SERIAL_B_ESP_FLASHING         OFF //    OFF, ON Upload ESP8266 WiFi firmware through SERIAL_B with :ESPFLASH# cmd.    Option
#define SERIAL_C_BAUD_DEFAULT         OFF //    OFF, n. Baud rate as above. See (src/pinmaps/) for Serial port assignments.   Infreq
#define SERIAL_D_BAUD_DEFAULT         OFF //    OFF, n. Baud rate as above. See (src/pinmaps/) for Serial port assignments.   Infreq
#define SERIAL_E_BAUD_DEFAULT         OFF //    OFF, n. Baud rate as above. See (src/pinmaps/) for Serial port assignments.   Infreq
#define SERIAL_RADIO                  OFF //    OFF, Use BLUETOOTH or WIFI_ACCESS_POINT or WIFI_STATION (ESP32 only.)         Option

// STATUS --------------------------------------------- see https://onstep.groups.io/g/main/wiki/Configuration_Controller#STATUS_LED
#define STATUS_LED                     ON //    OFF, Steady illumination if no error, blinks w/error code otherwise.          Option

// RETICLE CONTROL ------------------------------- see https://onstep.groups.io/g/main/wiki/Configuration_Controller#RETICLE_CONTROL
#define RETICLE_LED_DEFAULT           OFF //    OFF, n. Where n=0..255 (0..100%) activates feature sets default brightness.   Option
#define RETICLE_LED_MEMORY            OFF //    OFF, ON Remember reticle brightness across power cycles.                      Option
#define RETICLE_LED_INVERT            OFF //    OFF, ON Inverts control for cases where 0V is max brightness.                 Option

// WEATHER SENSOR --------------------------------- see https://onstep.groups.io/g/main/wiki/Configuration_Controller#WEATHER_SENSOR
#define WEATHER                      SHT31 //    OFF, BME280 (I2C 0x77,) BME280_0x76, BME280_SPI (see pinmap for CS.)          Option
                                          //         BMP280 (I2C 0x77,) BMP280_0x76, BMP280_SPI (see pinmap for CS.)
                                          //         SHT31 (I2C 0x44,) SHT31_0x45. Temperature and humidity, no pressure.
                                          //         BME280 or BMP280 for temperature, pressure.  BME280 for humidity also.

// SIGNALING ------------------------------------------- see https://onstep.groups.io/g/main/wiki/Configuration_Controller#SIGNALING
#define STEP_WAVE_FORM             SQUARE // SQUARE, PULSE Step signal wave form faster rates. SQUARE best signal integrity.  Adjust
                                          //         Applies to all axes.

// NON-VOLATILE MEMORY ---------------------------------------- see https://onstep.groups.io/g/main/wiki/Configuration_Controller#NV
#define NV_DRIVER              NV_DEFAULT // NV_DEF, Use platforms default non-volatile device to remember runtime settings.  Option
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

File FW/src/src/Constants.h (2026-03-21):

// -----------------------------------------------------------------------------------
// Constants
#pragma once

// Configuration options ----------------------------------------------------------------------------------------------------

// PINMAPS
#define PINMAP_FIRST                1

#define FYSETC_E4                   1      // FYSETC E4 Version 1.0, *** EXPERIMENTAL, MAY BE REMOVED AT ANY TIME ***

#define FYSETC_S6                   2      // FYSETC S6 Version 1.2, 3D printer board, a 6-axis design
#define FYSETC_S6_1                 3      // FYSETC S6 Version 1.2
#define FYSETC_S6_2                 4      // FYSETC S6 Version 2.0, 3D printer board, a 6-axis design

#define BTT_SKR_PRO                 5      // BigTreeTech SKR PRO Version 1.2
#define BTT_OCTOPUS_PRO             6      // BigTreeTech Octopus Pro Version 1.1

#define MiniPCB                     7      // small 2-axis design for embedded or mounting behind a panel, Teensy3.2
#define MiniPCB13                   8      // improved version 1.3 adds better support for ESP-01 flashing and optional I2C

#define MiniPCB2                    9      // 2-axis design for small alum. case, Teensy3.2

#define MaxPCB                      10     // first generation custom 4-axis board, Teensy3.5/Teensy3.6
#define MaxPCB2                     11     // second generation adds alum. case, Teensy3.5/Teensy3.6
#define MaxPCB3                     12     // third generation adds SPI four axis support, Teensy4.1
#define MaxPCB4                     13     // forth generation with SPI/TMC2209 support, Teensy4.1
#define RESERVED                    14     // RESERVED

#define MaxSTM3                     15     // update to the MaxPCB3 using an Blackpill F411CE instead of the Teensy3.5/3.6
#define MaxSTM3I                    16     // as above but using an onboard STM32F411CE with M24C64 EEPROM as default

#define MaxESP3                     17     // adds 4th axis and option to flash the WeMos D1 Mini WiFi through OnStep
#define MaxESP4                     18     // for ESP32S w/TMC2209 support
#define CNC3                        19     // Arduino CNC Sheild on WeMos D1 R32 (ESP32)
#define MicroScope                  20     // MicroScope PCB (ESP32, experimental and may be removed at any point!, USE AY YOUR OWN RISK!!!)

#define STM32Blue                   21     // Khalid and Dave's PCB for STM32 Blue pill (STM32F103CB and STM32F303CC)

#define JTWSTM                      22     // JTW Astronomy JTWSTM telescope mount controller Rev 2.1
#define MANTICORE                   23     // JTW Astronomy MANTICORE telescope mount controller Rev 1.0

#define SAL_XB1                     24     // SAL-XB1 telescope mount controller

#define AUB_FOCROT                  25     // AstroUniBoard Focuser/Rotator controller on STM32G0B1

#define PINMAP_LAST                 25

// WEATHER sensors (temperature, pressure, and humidity)
#define WEATHER_FIRST               1
#define BME280                      1      // BME280 on I2C (at default address 0x77)
#define BME280_0x77                 1      // BME280 on I2C (at address 0x77)
#define BME280_0x76                 2      // BME280 on I2C (at address 0x76)
#define BME280_SPI                  3      // BME280 on SPI (default CS)
#define BMP280                      4      // BMP280 on I2C (at default address 0x77)
#define BMP280_0x77                 4      // BMP280 on I2C (at address 0x77)
#define BMP280_0x76                 5      // BMP280 on I2C (at address 0x76)
#define BMP280_SPI                  6      // BMP280 on SPI (default CS)
#define SHT31                       7      // SHT31 on I2C (at default address 0x44)
#define SHT31_0x44                  7      // SHT31 on I2C (at address 0x44)
#define SHT31_0x45                  8      // SHT31 on I2C (at address 0x45)
#define WEATHER_LAST                8

// STEP WAVE FORM
#define STEP_WAVE_FORM_FIRST        1
#define SQUARE                      1
#define PULSE                       2
#define STEP_WAVE_FORM_LAST         2

// MOUNT TYPE
#define MOUNT_TYPE_FIRST            1
#define MOUNT_SUBTYPE_FIRST         1
#define GEM                         1      // German Equatorial Mount, meridian flips enabled
#define FORK                        2      // Fork Mount, meridian flips disabled
#define ALTAZM                      3      // Altitude Azimuth Mounts, Dobsonians, etc.
#define ALTALT                      4      // Altitude Altitude Mounts
#define MOUNT_SUBTYPE_LAST          4
#define GEM_TA                      5      // GEM, w/tangent arm Declination
#define GEM_TAC                     6      // GEM, w/tangent arm Declination and geometry correction
#define FORK_TA                     7      // FORK, w/tangent arm Declination
#define FORK_TAC                    8      // FORK, w/tangent arm Declination and geometry correction
#define ALTAZM_UNL                  9      // ALTAZM, w/unlimited Azmiuth motion
#define MOUNT_TYPE_LAST             9
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

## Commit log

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2026-05-19 feat: add MPU6000 IMU-based homing for Axis3 rotator
    - Add MPU6000 driver (I2C, atan2(-ax,-az) formula for face-up mounting)
    - Implement imuHome(): syncs axis3 from IMU, homes to gravity reference
    - Implement imuCalibrate(): :rHS# (sample) and :rHG# (gravity ref = 0deg)
    - Auto-home on boot (AXIS3_HOME_AUTO=ON), iterative correction passes
    - Config: AXIS3_LIMIT_MIN=0, AXIS3_LIMIT_MAX=360 (ASCOM/NINA compatible)
    - Add :rHD# diagnostic command for imuHome() snapshot
    Key fix: chip is mounted face-up (az=-g at landscape), requiring negated
    formula atan2(-ax,-az) to read 0deg at landscape and +-180deg upside-down.
2026-11-05 feat(hw): rev 2.0 schematic reorganisation, review fixes and PCB clean-up
    Schematic
    - Rebuilt as one tidy A2 sheet in function blocks with named nets; symbol
    UUIDs/refs/footprints kept, custom symbols moved to project library
    astrouniboard.kicad_sym (stale myLib entry dropped from sym-lib-table).
    - +5V3 buck set to 5.29 V (R22 10k, R23 1k78).
    - TMC2209 SPREAD/STDBY tied to GND, INDEX and DIAG unused.
    - Downstream USB-C: USBLC6-2SC6 ESD (U9), CC pull-ups 56k (default power).
    - JP5 (+12V -> Vdrive) bridged by default.
    - EEPROM WP to GND (24AA64-OT symbol), C69 100nF for SHT31 supply,
    Y2 case to GND, C67/C68 DNP (CH334 has built-in load caps).
    - LEDs dimmed to ~0.3 mA; R/C symbols unified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
2026-11-05 fix(tools): firmware manager DFU result detection and portable tool paths
    - Treat 'File downloaded successfully' as success: dfu-util exits non-zero on
    STM32G0 because the device reboots before the final status read.
    - Report build failures from the return code instead of exceptions.
    - Find dfu-util and pio on PATH first, then in the PlatformIO install of the
    current user, instead of a hard-coded user path.
2026-11-05 fix(fw): invert IMU gravity vector in rotator homing angle
    atan2 of the negated X/Z averages so the computed angle matches the physical
    rotator orientation used by imuHome().
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2026-11-05 fix(hw): tidy USB-C D+/D- fan-outs at J7 and J2
    - J7 D+: one 45-degree drop onto the A6/B6 bridge instead of four 0.03-0.25 mm
    jogs at three slightly different heights; straight stub into A6.
    - J2 D+/D-: vias moved onto the track line, micro-jogs replaced by straight
    runs. DRC and schematic parity unchanged.
2026-11-05 fix(hw): simplify jogged tracks and straighten off-grid pad/via entries
    Automated, DRC-gated clean-up (every change checked against clearance,
    hole spacing and schematic parity):
    - 38 track chains replaced by the simplest 45-degree path between their fixed
    ends (never longer than before), 1450 -> 1361 segments.
    - 14 off-angle pad entries straightened by moving the end point inside the pad.
    - 3 Vdrive1 vias nudged 0.005-0.03 mm onto their track lines.
    Off-45 segments 34 -> 18; remaining flags are short 45-degree chamfers.
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2026-11-06 docs: firmware V2 plan and GitHub issue index
    Plan to replace OnStepX with own firmware (OpenWheel-style :NN# protocol),
    ASCOM/INDI drivers and the Secondary Focuser NINA plugin, with all
    interview decisions. Issues #1-#54 track the work.
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2026-11-06 feat(fw): V2 firmware skeleton with SHT31 readout
    New fw/ PlatformIO project for HW rev 2.0 (USB CDC 1209:0001, 8 MHz HSE
    clock config from OpenWheel, OpenWheel framing and error codes).
    SHT31 driver reads the on-board (0x45) and external J9 (0x44) sensor
    every 2 s, non-blocking, with CRC check, dew point and a supply power
    cycle on PB9 after 3 on-board failures. Temporary :90# reports both
    until the env block is specified (#10). Motor drivers held disabled.
    docs/HARDWARE.md: rotator pins are PB13/14/15, SHT31 addresses per
    rev, SHT_PWR PB9, EEPROM address to be confirmed by bus scan.
    Refs #34, #14
2026-11-06 feat(fw): magic-word DFU, watchdog safe mode, SHT31 fix on hardware
    - :31# stores a magic word in TAMP BKP0R and resets; SystemClock_Config
    jumps to the system bootloader before clocks/USB are set up. :22# reboots.
    - 4 s IWDG + progress marker in BKP1R; after a watchdog reset the fw
    starts without sensors so USB and :31# stay reachable. Temporary :99#
    reports reset flags, last marker and a bring-up note. PB4 heartbeat.
    - SHT31: restart Wire after a failed transfer. A NACK from the absent
    on-board sensor made the next transfer to 0x44 starve the main loop.
    Supply power cycle only for a sensor that answered before.
    Tested on a rev 1 board (U8 not fitted, SHT31 on J9): 25.5 C, 43 %RH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
2026-11-06 docs: PROTOCOL.md draft — framing, USB identity, common block, error codes
    OpenWheel-family framing and reply style; common commands keep OpenWheel
    numbers. Defines identify with caps, the V2 status line, housekeeping
    (OpenWheel fields + per-driver temps), per-axis StallGuard, and :46#
    reset/safe-mode info replacing the bring-up :99#. Lists the differences
    from OpenWheel and the points still open for review.
    Refs #7
2026-11-06 docs: protocol focuser block 50-69 and per-axis driver config :47/:48
    Focuser: position, absolute/relative moves without clamping, halt, max,
    sync, speed, acceleration, backlash take-up, reverse, stored step size.
    Defaults from the V1 OnStepX setup, StealthChop for StallGuard.
    Common :47/:48 hold TMC2209 current, microsteps, mode and idle-off per
    axis so the rotator block reuses them. Records the §8 review decisions.
    Refs #7, #8
2026-11-06 docs: complete protocol 1.0 — rotator, environment/IMU, error codes, USB IDs
    - Rotator 70-89: signed mechanical angle in cdeg, cable-wrap rule for
    :71 targets, sync/set home, IMU home with tolerance and passes, boot
    home, steps per 1000 degrees; defaults from the V1 Triton setup.
    - Environment/IMU 90-99: selected-sensor reading for drivers, both SHT31
    sensors for the debug app, automatic IMU zero calibration (g0 + rotation
    axis from a +90 degree move), roll/tilt readout.
    - Error code 15 (optical axis near vertical); error_codes.h lists every
    code of the table.
    - docs/USB_IDS.md, linked from README.
    Closes #9, closes #10, closes #11, closes #12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
2026-11-06 feat(fw): V2 skeleton — block dispatch, frozen module interfaces, stubs
    - protocol.cpp keeps framing/replies and routes 20-49/50-69/70-89/90-99 to
    protocol_common/focuser/rotator/env.cpp; line limit 46 chars per spec
    - frozen headers: status, settings (defaults from PROTOCOL.md 4.1/4.2), axis,
    step_timer, tmc2209, focuser, rotator, rotator_wrap, imu_mpu6000, nv_store,
    housekeeping, leds; stub .cpp files compile
    - temporary :90# SHT31 command is now :91# (V,...); :99# replaced by :46#
    - native env for host unit tests; fw/MODULES.md module map
    Builds: flash 38.2% (50028 B), RAM 3.5%.
    Refs #16
2026-11-06 feat(fw): NV store on the 24AA64 with CRC records and a position ring
    Probes 0x50 then 0x57. Settings and IMU calibration records carry magic,
    version, length and CRC-16; an older, shorter record migrates by prefix.
    Positions go to a 256-slot ring with sequence numbers and moving bits;
    writes use ACK polling, position slots are written from nvUpdate().
    Refs #17
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2026-11-06 feat(fw): LED dimming on TIM16 soft PWM and blink patterns
    Status LED on, 5 Hz on a sticky error; activity heartbeat 1 Hz (4 Hz safe
    mode), 10 Hz while an axis is busy.
    Refs #20
2026-11-06 feat(fw): common protocol block 23-48
    :23 save, :24 defaults with microstep rescale, :30 halt, :32 identify with
    the USB serial, :33 status, :34 error, :40 housekeeping, :41/:42 StallGuard,
    :43/:44 LED brightness, :47/:48 driver config (idle_off 0..3600 s).
    Refs #16 #17 #18 #20
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2026-11-06 feat(imu): MPU-6000 accelerometer driver on I2C
    WHO_AM_I probe, wake with internal oscillator, gyro standby, accel +-2 g,
    DLPF 10 Hz, 50 Hz. One short transfer per imuUpdate() call, EMA low-pass
    in mg, settling counter for the rotator, PWR_MGMT_1 check every second,
    re-probe every second while not answering (rev 1 /CS floats: I2C mode
    must be verified on the board). Calibration captures and finish glue,
    calibration loaded at begin.
    Refs #31, #32
2026-11-06 feat(env): sensor selection and the 90-99 protocol block
    envSelected() follows settings.envSelect (auto prefers J9, falls back to
    on-board). :90 W record, :92/:93 selection, :94 IMU reading, :95 runs the
    rotator calibration, :96 calibration data, 97-99 ERR,10, ERR,7 for
    unexpected parameters. SHT31: restart Wire also after a failed read.
    Refs #34, #31, #32
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2026-11-06 feat(fw): TIM3 step generator and axis with trapezoid ramp, halt, idle-off
    One TIM3 update IRQ per step (no ARR preload, 8 MHz ticks, long periods split
    into silent chunks). AVR446 integer ramp in the ISR, triangle for short moves,
    halt() decelerates over the steps used to accelerate, exact step count,
    uncounted lead steps, EN settle 2 ms, idle-off timer. Step rate clamped to 50 kHz.
    Refs #23
2026-11-06 feat(fw): TMC2209 UART config, idle health polling and StallGuard
    Vendored TMCStepper from OpenWheel. tmcApply writes currents (integer IRUN/IHOLD
    with vsense), MRES, StealthChop/SpreadCycle, SGTHRS/TCOOLTHRS and verifies IOIN.
    Idle: one driver per 500 ms, GSTAT reset -> re-apply + latched warning, temp
    class, otpw. During a move: SG_RESULT every 20 ms (stats, stall stop after 200 ms
    above the minimum speed), DRV_STATUS every 100 ms (fault -> stop + error 5).
    Refs #24 #27
2026-11-06 feat(fw): focuser moves, backlash, persistence and protocol block 50-69
    Soft limits without clamping, ERR,7/8, backlash lead steps on a direction change,
    position restored at boot with the unverified flag, nvMarkMoving before a move,
    save 2 s after a stop, sync saves at once, rescale on a microstep change.
    Refs #25 #26
2026-11-06 perf(fw): run the I2C bus at 400 kHz
    The NV store reads the whole position ring at boot (~0.4 s at 100 kHz).
    A bus restart after an error falls back to the Wire default of 100 kHz.
2026-11-06 fix(nv): treat a foreign record magic as blank, not as an EEPROM fault
    Found on the rev 1 board: the IMU record area still held fw-onstepx data,
    so FLAG_EEPROM_FAULT stayed set although the settings record was fine.
    Our own magic with a bad version/length/CRC is still a fault.
    EEPROM answers at 0x50 on the rev 1 board.
    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
2026-11-06 fix(fw): review findings — position record, driver hold, I2C clock, error codes
    - nv/focuser: the position slot stores the focuser microstep setting and an
    "unverified" bit. A :48 / :24 microstep change that is not saved with :23#
    is scaled back at boot; a stall (or a never-synced position) stays
    unverified across a reboot until :56. focuserRescale() saves on the next
    loop pass, after the new microstep value is stored.
    - axis: idle_off 0 keeps the driver enabled from power-on (rotator holds the
    camera before the first move) and when idle_off is set to 0.
    - i2c_bus: one i2cRestart() for the STM32duino Wire workaround, used by the
    SHT31 and IMU code; it restores 400 kHz (Wire.beg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
2026-11-06 feat(protocol): identify gate — ERR,16 until :32#, protocol version 2
    After a reset only :25# ping and :32# identify are accepted; every other
    command answers ERR,16 (not identified, same number as OpenWheel) until
    :32# has been answered. Re-locks only at reset: measured on the board,
    pyserial sends SET_LINE_CODING on open but also on every timeout or baud
    change, so a port open cannot be detected reliably.
    hwtest: reconnect by USB serial number and identify; new test for the gate
    after a reboot; identify expects protocol 2.
    Refs #58
2026-11-06 fix(tmc): StallGuard statistics count only samples the stall check uses
    At start-up and slow-down SG_RESULT reads near 0, so :41 min was ~0 and
    "a third of the lowest min" gave a useless threshold. Measured with motors
    on the rev 1 board: focuser cruise 48..136 at 900 steps/s. The rotator at its
    default 12 deg/s runs below the 100 full steps/s StallGuard minimum, so it
    reports no samples.
    Refs #27
2026-11-06 docs(protocol): 2.0 — identify gate, ERR,16, three-capture IMU calibration
    Also records the StallGuard measurements from the rev 1 board (focuser
    cruise readings, hand block not detected, rotator below minimum speed).
    Refs #58 #32 #27
2026-11-06 feat(imu): measure roll from the gravity circle centre (accelerometer offset)
    The three calibration captures give the circumcentre of the gravity circle;
    its part in the plane normal to n is the accelerometer offset there. Roll
    and tilt are now measured from it. IMU record version 2 (+ c[3]); version 1
    records load with c = 0. :96 appends cx,cy,cz.
    Rev 1 board, rotator turning the board: offset (37, -1, -64) mg. Roll error
    at +40/+90/+170/-40/-120/-170 deg was -1.4/-4.8/-7.8/-0.6/-5.6/-7.0 deg,
    now +0.1/-0.4/+0.5/+0.3/+0.7/+1.4 deg. Unit tests (WSL g++) 9/9; hwtest 87.
    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
2026-11-06 feat(tools): firmware_manager updates V2 boards via :32# + :31#
    Detect V1 (OnStepX) vs V2 per port: 1209:0001 and an ASTROUNIBOARD
    identify reply mean V2, other USB ids are V1 and are not probed. V2 gets
    :32# then :31# on one open port (identify gate re-locks on open), with one
    re-identify retry on ERR,16. Flash the fw/ rev2 build with dfu-util
    (-d 0483:df11), wait for the bootloader instead of a fixed sleep, then wait
    for the same USB serial number and check the :32# firmware field against
    FIRMWARE_ID in fw/src/config.h. Adds hardware-free unit tests and updates
    the README.
    Tested on a rev 2 board (COM9): FW2.0.0 -> FW2.0.99 -> FW2.0.0.
    Refs #19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
2026-11-06 fix(ci): pin ststm32 19.6.0 and track OnStepX Plugins.config.h
    CI installed a newer ststm32 whose Arduino core rejects HardwareSerial(rx, tx);
    pin the version the boards were tested with. OnStepX's own .gitignore kept
    src/plugins/Plugins.config.h out of git, so a clean checkout of fw-onstepx/
    never built.
    Refs #5
2026-11-06 feat(host): AstroUniBoard.Core — transport, detection, worker, protocol 2.0
    Copy & adapt of OpenWheel.Core (net48, no ASCOM dependency):
    - serial link and framing with bounded timeouts
    - USB detection on 1209:0001 + :32# identify (rejects an OpenWheel on the
    shared test PID), reconnects only to the same USB serial
    - BoardController worker: cached snapshot (status, housekeeping,
    environment, focuser/rotator settings), bounded commands for both axes,
    IMU home/calibration, driver config, StallGuard, raw console, reboot, DFU
    - identify gate: ERR,16 -> re-identify (same serial) and repeat once
    - circuit breaker (3 bad replies -> reconnect with backoff), move watchdog
    - 49 xUnit tests with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
2026-11-06 feat(sim): Python device simulator for protocol 2.0 (Refs #39)
    Fake AstroUniBoard for host tests (V2_PLAN Q08) in driver/sim: a model of
    firmware V2 copied from fw/src (identify gate, common/focuser/rotator/env
    blocks, ramps, backlash, cable wrap, IMU home and calibration, StallGuard,
    EEPROM persistence, reboot/DFU), served on a pty (POSIX), TCP (any OS) or a
    COM port via pyserial (com0com). Link fault injection and world controls on
    stdin or Simulator.control(). pytest suite and a sim CI workflow.
2026-11-06 docs(protocol): match the firmware on identify version, busy rules and :95 errors
    - identify example and the OpenWheel comparison table say protocol 2
    - :56 sync and :65 reverse answer ERR,8 only while the focuser moves; :55
    floor rule during a move; setters without a busy check are listed
    - :95 can answer ERR,7 (needs 180 deg of cable wrap above the angle)
    - state 0 is only seen before USB is up
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2026-11-06 feat(debug-app): control & debug app over the ASCOM driver or direct (#45)
    WinForms net48 app in driver/ASCOM/AstroUniBoard.DebugApp, added to the solution.
    - IBoardSession with two paths: AscomSession (late-bound COM to
    ASCOM.AstroUniBoard.Focuser, only the AstroUniBoard:Raw/Snapshot/Log/... Action
    contract, works while N.I.N.A. is connected) and DirectSession (own
    BoardController; takes the port). LoopbackDriver is a reference implementation
    of the contract over a BoardController (--loopback, tests).
    - Tabs: status with decoded flags, error + clear, housekeeping, reset info;
    focuser and rotator jog/move/halt/sync/set home and settings with save;
    TMC2209 config and StallGuard w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
2026-11-06 fix(ascom): align Action contract with the debug app, UAC fallback for /regserver
    Raw returns the reply without '#', status keys rotatorAngle/rotatorTarget (Core names),
    EnterDfu keeps looking for the board while clients are connected. /regserver relaunches
    with runas when IsInRole says admin but the registry write is denied. Ignore driver/ASCOM/dist/.
2026-11-06 fix(debug-app): read the LocalServer's log times as local time
    The driver's AstroUniBoard:Log sends ISO times without an offset (local).
    Adds a test with the LocalServer's exact snapshot JSON (state as enum name,
    stateCode, host object).
    Refs #45
2026-11-06 feat(hw): fix missing 3D models on rev 2.1 board
    Point broken (model ...) entries at existing models so renders are complete:
    - U2/U3 TMC2209: stock QFN-28-1EP_5x5mm_P0.5mm_EP3.35x3.35mm (same body)
    - J2/J7 GT-USB-7010ASV: stock GCT USB4105 16P top-mount (pad-identical)
    - U6 CH334P: stock QFN-16-1EP_3x3mm_P0.5mm_EP1.7x1.7mm
    - U10 MPU-6000: stock QFN-24-1EP_4x4mm_P0.5mm_EP2.7x2.7mm
    - L4: IHLP-2020 .step instead of the dropped KiCad6 .wrl
    - R10/R11: R_0805 .step instead of the dropped KiCad6 .wrl
    - U8 SHT31: official Sensirion SHT3x STEP from the shared library,
    rotated -90 deg about X (pin-1 chamfer matches the footprint)
    Only model entries changed; DRC unchanged. J6 (XT30PW-M) still has n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
2026-11-06 test(debug-app): read-only check against the installed LocalServer
    Connects next to another client, reads identify/status/housekeeping/IMU/
    environment/StallGuard/log, checks rejected commands and that closing the app
    leaves the other client connected. Screenshots retaken through the real driver.
    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
2026-11-06 docs(ascom): SPEC.md, ConformU 4.5.2 reports for Focuser, Rotator, ObservingConditions
    All three: 0 errors, 0 issues, all members within target times (board FW2.0.0 on COM9).
    ObservingConditions DeviceState no longer lists TimeSinceLastUpdate (ConformU issue).
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2026-11-06 feat(hw): add XT30PW-M 3D model for J6
    KiCad 10 ships the AMASS XT30PW-M footprint without a model. Use the
    SnapEDA STEP (shared library amass.3dshapes), rotated -90 deg about X and
    offset (-2.5, 10, 0) so the pins and mounting pegs sit in their holes.
    Only the J6 model entry changed; DRC unchanged.
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2026-11-06 fix(hw): restore component outlines, move 5V/12V labels, unify TMC2209 footprint
    - Restore silkscreen outlines on all fitted parts (incl. J5, J2, J7);
    unfitted JSTs and the XT30 stay without outline, refdes/values stay hidden
    - Move the 5V/12V jumper labels off the capacitor pads next to JP4/JP5
    - Replace U3 with the KiCad 10 QFN-28 ThermalVias footprint so it matches
    U2 (3x3 paste grid); thermal-via drill set to 0.3 mm like U2
2026-11-06 fix(sim): shut the TCP listener down on unplug so Linux stops accepting
    close() from the control thread leaves the listener alive while the serving
    thread is still in select() on it; a host that reconnects at once lands in
    its backlog and is reset. Fixes test_powercut_loses_unsaved_position on
    ubuntu-latest (60/60 resets before, 0/60 after, WSL Ubuntu).
2026-11-06 docs: public README with renders, BOM and assembly guide
    - KiCad 10 renders of rev 2.1 as delivered (DNP sockets hidden): top, bottom,
    board edge and a side view of the J5 / XT30 stack; schematic PDF
    - feature table with the reason for each part, alternatives considered
    - connector and jumper pinout, full BOM with LCSC numbers and stock notes
    - assembly: J5 before the XT30 (its pins end under the XT30 body),
    never JP4 and JP5 together, first power-up checklist
    - replaces stale facts (93 % flash, WinUSB, OnStep clients, tools/)
    Refs #35
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2026-11-06 feat(driver): image and dfu-util checks, no reset while moving, Alpaca rule
    - DfuUpdater.CheckImage checks the vector table (initial SP in SRAM, odd reset
    vector inside the flash and the image) and the ASTROUNIBOARD-IMG:<model>;
    marker against the identify reply: a missing marker needs the user's OK,
    another model is blocked unless forced (#79).
    - FindDfuUtil prefers the copy next to the app, skips relative PATH entries,
    logs the full path; the app asks before using one from PATH/PlatformIO.
    The installer ships dfu-util 0.11 + libusb with the GPL licence and source
    links (#79).
    - BoardController refuses :22#/:31# (Reboot, EnterDfu, Raw) while an axis
    moves; Raw expects a reset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
2026-11-06 chore(hw): drop stale production outputs, ship them as release assets
    hw/production/ held the rev 1 outputs (barrel jack, no LCSC numbers).
    Production files are no longer committed: hw/production/ is ignored and
    each ordered revision attaches the JLC zip, BOM and CPL to its hw-rev<x.y>
    release. HARDWARE.md describes how to generate and check them; the toolkit
    options now exclude DNP parts.
    Checked with the rev 2.1 board: every BOM line has an LCSC number,
    H1-H8 and the DNP connectors are out of BOM and CPL.
    Closes #73
2026-11-06 fix(fw): move safety — driver check, suspect angle guard, safe-mode moves, busy reboot
    - #74: rotator moves (also IMU home / calibration) check the TMC2209 like the focuser
    (ERR,5 + sticky). New env rev21 (-D HW_REV=21) reads +12 V on PB10 and refuses moves
    on both axes below 9 V (hk warning bit4); rev2 unchanged.
    - #75: rotator "suspect" angle (status flag 9): power loss mid-move, stall/fault stop,
    never saved, safe mode; saved across reboots. While suspect and the new guard setting
    is on (default 1, :97 / :98), :71 / :72 / :95 answer ERR,17 until :76 sync or :77 home.
    Settings record version 2 (padding-safe migration from version 1).
    - #76: :22# / :31# answer ERR,8 while any ax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
2026-11-06 feat(hw): rev 2.1 review fixes - 3-pad motor supply jumper, 12 V input TVS
    Folded into rev 2.1 (not ordered yet) instead of a rev 2.2:
    - JP4/JP5 -> one 3-pad solder jumper JP4 (+12V - Vdrive - +5V, 1-2
    bridged), so the motor supply can't tie +12 V to the 5 V rail (#70).
    JP4 sits where JP5 was; C56 moved right; the board's +12 V row is now
    fed from the XT30 + pin over B.Cu and two vias.
    - D24 SMAJ15A (C86819) TVS across J6 on the bottom side, cathode towards
    the XT30 + pin (#71). Owner's choice: TVS only, no reverse FET/PTC.
    - J5/XT30 stacking stays (no room for a drop-in fix); bottom silkscreen
    "J5 FIRST" next to the XT30 (#69).
    - No SWD pads (#72, owner's choice: DFU only).
    DRC: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
2026-11-06 feat(hw): 12 V input polyfuse F1, TVS D24 to SMF15A on top
    Owner's layout (top-side assembly only):
    - F1 Ruilon SMD1206P200TF/16 (C55125664, 2 A hold / 3.5 A trip, 16 V)
    between the XT30 + pin (new net VIN) and +12V.
    - D24 now SMF15A in SOD-123FL (C123802) after the fuse, on the top side
    between the XT30 pins; nothing is left on the bottom side.
    - Accepted layout notes: F1 connects to the XT30 + pad by pad overlap;
    D24's GND pad is 0.15 mm from the + pad (hand-soldering warning added to
    the README assembly steps); the +12V vias to the B.Cu feed sit in JP4's
    12 V pad.
    DRC: errors only the known M2/M3 hole_to_hole; schematic parity clean.
    README (power path, connectors, BOM, assembl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
